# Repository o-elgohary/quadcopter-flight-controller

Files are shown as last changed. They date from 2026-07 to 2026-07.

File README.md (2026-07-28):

# Quadcopter Flight Controller

A 250mm-class quad flight controller, designed across three connected pieces: a custom PCB, a 3D-printed frame, and a control-systems simulation. None of this has been physically built or flown. It's a design and simulation project, stated plainly rather than implied otherwise.

## The integration story

The point of this project isn't any single piece, it's that each piece drove a real decision in another:

- **The simulation's control-loop speed requirement decided a wiring choice on the PCB.** The rate loop runs at 500Hz, which means the IMU needs to report data faster than 1kHz to keep up. That's why the ICM-42688-P is wired on SPI1 instead of I2C in the schematic, since I2C can't reliably keep pace with a loop that fast once you account for register-read overhead.
- **The PCB's real mounting-hole positions drove the CAD frame's geometry.** The board's STEP export (`pcb/exports/board.step`, once routing is finished) gets imported directly into the Fusion 360 frame model, and the center plate's mounting pattern is dimensioned straight off it, not measured by eye.
- **Every number in every phase traces back to one file, `spec.md`**, so a change to (say) the battery or frame size ripples outward instead of getting silently re-typed as a new assumption somewhere else.

## Repo layout

```
spec.md         master numbers every other file pulls from
pcb/            KiCad schematic + layout
cad/            exported Fusion 360 frame STEP
sim/            Python attitude-recovery simulation
```

## Status

| Phase | State |
|---|---|
| Spec (`spec.md`) | Done. Frame/motor/battery/IMU/MCU choices are real parts for this class of build; motor thrust/torque constants (kT, kQ) are documented estimates anchored to real bench-test data, not measured on this exact hardware. |
| PCB (`pcb/`) | Schematic done, ERC clean (0 errors, 2 benign warnings). Board outline, mounting holes, and component placement are done. Copper routing is not finished, so real DRC violations remain from auto-placement, left as the next real routing pass rather than papered over. |
| Frame (`cad/`) | Modeled in Fusion 360: center plate with the PCB's mounting pattern, 4 arms sized to the 250mm diagonal, motor mounts, battery deck. Exported to `cad/exports/frame_assembly.step`. Prop clearance checked analytically (adjacent motors clear by about 50mm at the prop tips). |
| Simulation (`sim/`) | A single-axis PD controller recovering a 20° tilt, settling in 0.13s. Deliberately simplified from an earlier, much larger 6-DOF version, see `sim/README.md` for why. Produces a plot (`sim/exports/recovery.png`). |

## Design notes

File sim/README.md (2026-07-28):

# Quadcopter Flight Controller - Simulation (Phase 3)

A minimal single-axis attitude simulation: a PD controller recovering a
quadcopter from an initial tilt. Simplified on purpose, see "Why simplified"
below. Every physical constant traces back to `../spec.md`.

## Files

| File | Role |
|---|---|
| `quad_sim.py` | Everything: constants, the PD control loop, and the plot. |

Run it from this `sim/` directory:

```
python -m venv .venv
.venv/Scripts/pip install -r requirements.txt
.venv/Scripts/python quad_sim.py
```

Writes `exports/recovery.png` (tilt angle vs. time, with the settling point
marked).

An animated version (drone icon banking back to level) was attempted but
dropped. matplotlib's GIF-writing path (`animation.PillowWriter`, a manual
canvas-buffer grab, and a `savefig`-per-frame plus Pillow `save_all` combine)
all silently produced a GIF where every frame showed the same final state,
in this specific environment. Root cause wasn't nailed down after several
different fixes, so the static plot below reliably shows the same result
without depending on that broken path.

## Results

Recovering from a 20 deg initial tilt, PD control settles within a 2 deg band
at **t = 0.13 s**.

Gains (in `quad_sim.py`): `KP = 0.5`, `KD = 0.035`. No integral term, since
this model is deliberately simple enough that a small P+D loop is enough to
show the point, and skipping I avoids windup entirely rather than adding an
anti-windup clamp for a demo this small.

## Why simplified

An earlier version of this modeled full 6-DOF coupled dynamics across 8 files
(quaternion attitude, IMU sensor noise, a complementary filter, cascaded
dual-rate PID, a 3D video render), around 700 lines. That was cut down to
this single ~110-line file on purpose. It keeps the same core idea (a
tilted quad correcting itself via feedback control) without machinery that
made the project harder to explain than it needed to be for its scope.

## What's estimated vs. from spec.md

From `spec.md` directly: mass (0.650 kg), arm length (0.125 m, half the
250 mm diagonal), control loop rate (500 Hz).

Estimated here (not in spec.md, no CAD to measure from): the per-axis
rotational inertia, modeled as just the 4 motors (30 g each) as point masses
at the arm tips, 45 deg off-axis in the X layout: `I = 4 * m_motor *
(ARM * sin(45°))^2`. This ignores the central body's own inertia contribution,
which is a real simplification, not an oversight. It keeps the number easy
to derive and explain, at the cost of being a slight underestimate. The PD
gains were tuned against this specific number, so if the inertia estimate is
refined later, the gains would need retuning too.

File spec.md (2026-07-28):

# Spec - Quadcopter Flight Controller

Every number used in `pcb/`, `cad/`, and `sim/` should trace back to this file. If you change something here, it should ripple out to the other phases, not get re-typed as a new magic number somewhere else.

## Airframe

| Parameter | Value |
|---|---|
| Frame class | 250 mm motor-to-motor diagonal (X config) |
| Motors | 2306, 2400 KV, 4x |
| Props | 5" (127 mm) |
| Battery | 4S LiPo, 1500 mAh, 14.8 V nominal |
| Target all-up weight (AUW) | ~650 g |
| Hover thrust per motor | ~1.6 N (650 g x 9.81 / 4) |

## Motor model

Real thrust-stand data for 2306/2400KV motors on 5" props (Emax RS2306 2400kv family, tested on miniquadtestbench.com) tops out around 1100-1400 g of thrust per motor at full throttle on 4S. That's the anchor point for the estimate below. I don't have a datasheet-grade thrust curve for this exact motor/prop/battery combo, so I derived kT and kQ instead of inventing precise-looking numbers. Treat these as reasonable-order-of-magnitude estimates, not verified hardware values.

Method:
- No-load speed at 4S: 2400 KV x 14.8 V ≈ 35,500 RPM. Under a real 5" prop load, racing motors typically sag to somewhere around 28,000 RPM at max sustained throttle.
- Picking max thrust ≈ 13 N (~1325 g, middle of the observed 1100-1400 g range) at ω_max ≈ 2930 rad/s gives:
  - **kT ≈ 1.5e-6 N·s²/rad²** (F = kT · ω²)
- Reaction torque (yaw authority) uses the common rule-of-thumb that a 5" multirotor prop's drag torque is roughly 3-8% of its thrust times the prop radius:
  - **kQ ≈ 7.5e-8 N·m·s²/rad²**
- Working these backwards, hover (1.6 N/motor) lands at ω_hover ≈ 1030 rad/s ≈ 9,800 RPM, which is about 28% of max RPM. That's a plausible hover throttle for a racing motor on a light 650 g frame (these motors are deliberately overpowered for punch-outs and recovery authority, so low hover throttle is expected, not a bug).
- Motor electrical/mechanical lag: **τ ≈ 0.02 s** (typical first-order response time for small FPV motor + ESC combos, per brief).

## Control loop rates

- Rate (inner) loop: 500 Hz
- Attitude (outer) loop: 250 Hz
- Rule used: IMU output data rate must be > 2x the fastest loop (500 Hz), so > 1 kHz minimum.

## IMU choice

ICM-42688-P, SPI. Datasheet specs (TDK InvenSense):
- Gyro noise density: 2.8 mdps/√Hz
- Accel noise density: 70 µg/√Hz
- Max ODR: 32 kHz (we'll run it far below that, e.g. 1-2 kHz, but it comfortably clears the >1 kHz requirement above)

This is why the IMU is on SPI1 rather than I2C in the schematic. I2C tops out well below what a 500 Hz rate loop wants once you account for register-read overhead.

## Barometer

BMP280 on I2C1 (altitude only, not latency-critical, so I2C is fine here).

## MCU

STM32F411CEU6, UFQFPN48. 100 MHz Cortex-M4F, enough headroom for 500 Hz control math plus sensor fusion.

## Board

- 36x36 mm outline
- 30.5x30.5 mm M3 mounting hole pattern (standard "FC30.5" footprint; this exact number is reused for the CAD frame's standoff pattern in Phase 2)

## Open assumptions to flag if anyone pushes back on this spec

- kT/kQ are derived estimates, not measured on this exact motor/prop/battery combination.
- τ (motor time constant) is a typical-value assumption, not measured.
- Everything else (frame size, battery, MCU, IMU, board size/hole pattern) is a normal, real part choice for this class of build.

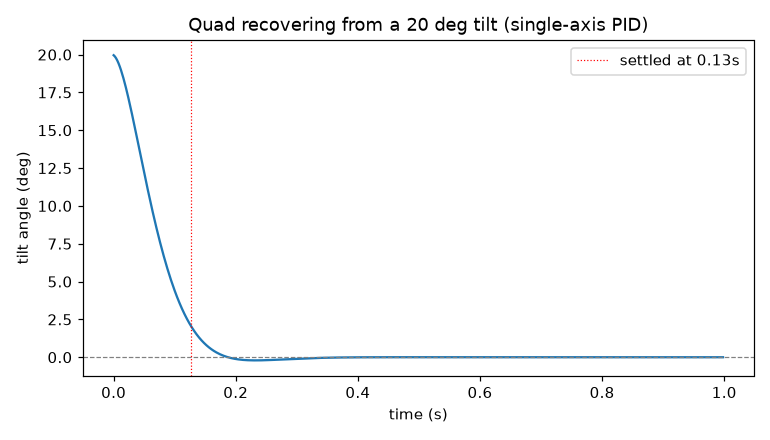
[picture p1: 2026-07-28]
sim/exports/recovery.png

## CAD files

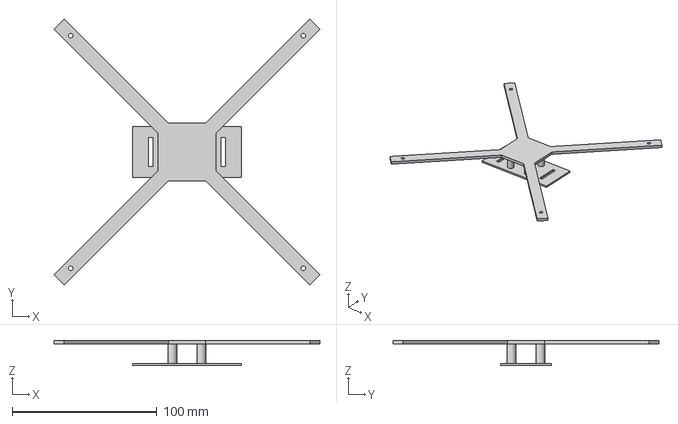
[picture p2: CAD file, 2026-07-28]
cad/exports/frame_assembly.step
183.8 x 183.8 x 17.5 mm

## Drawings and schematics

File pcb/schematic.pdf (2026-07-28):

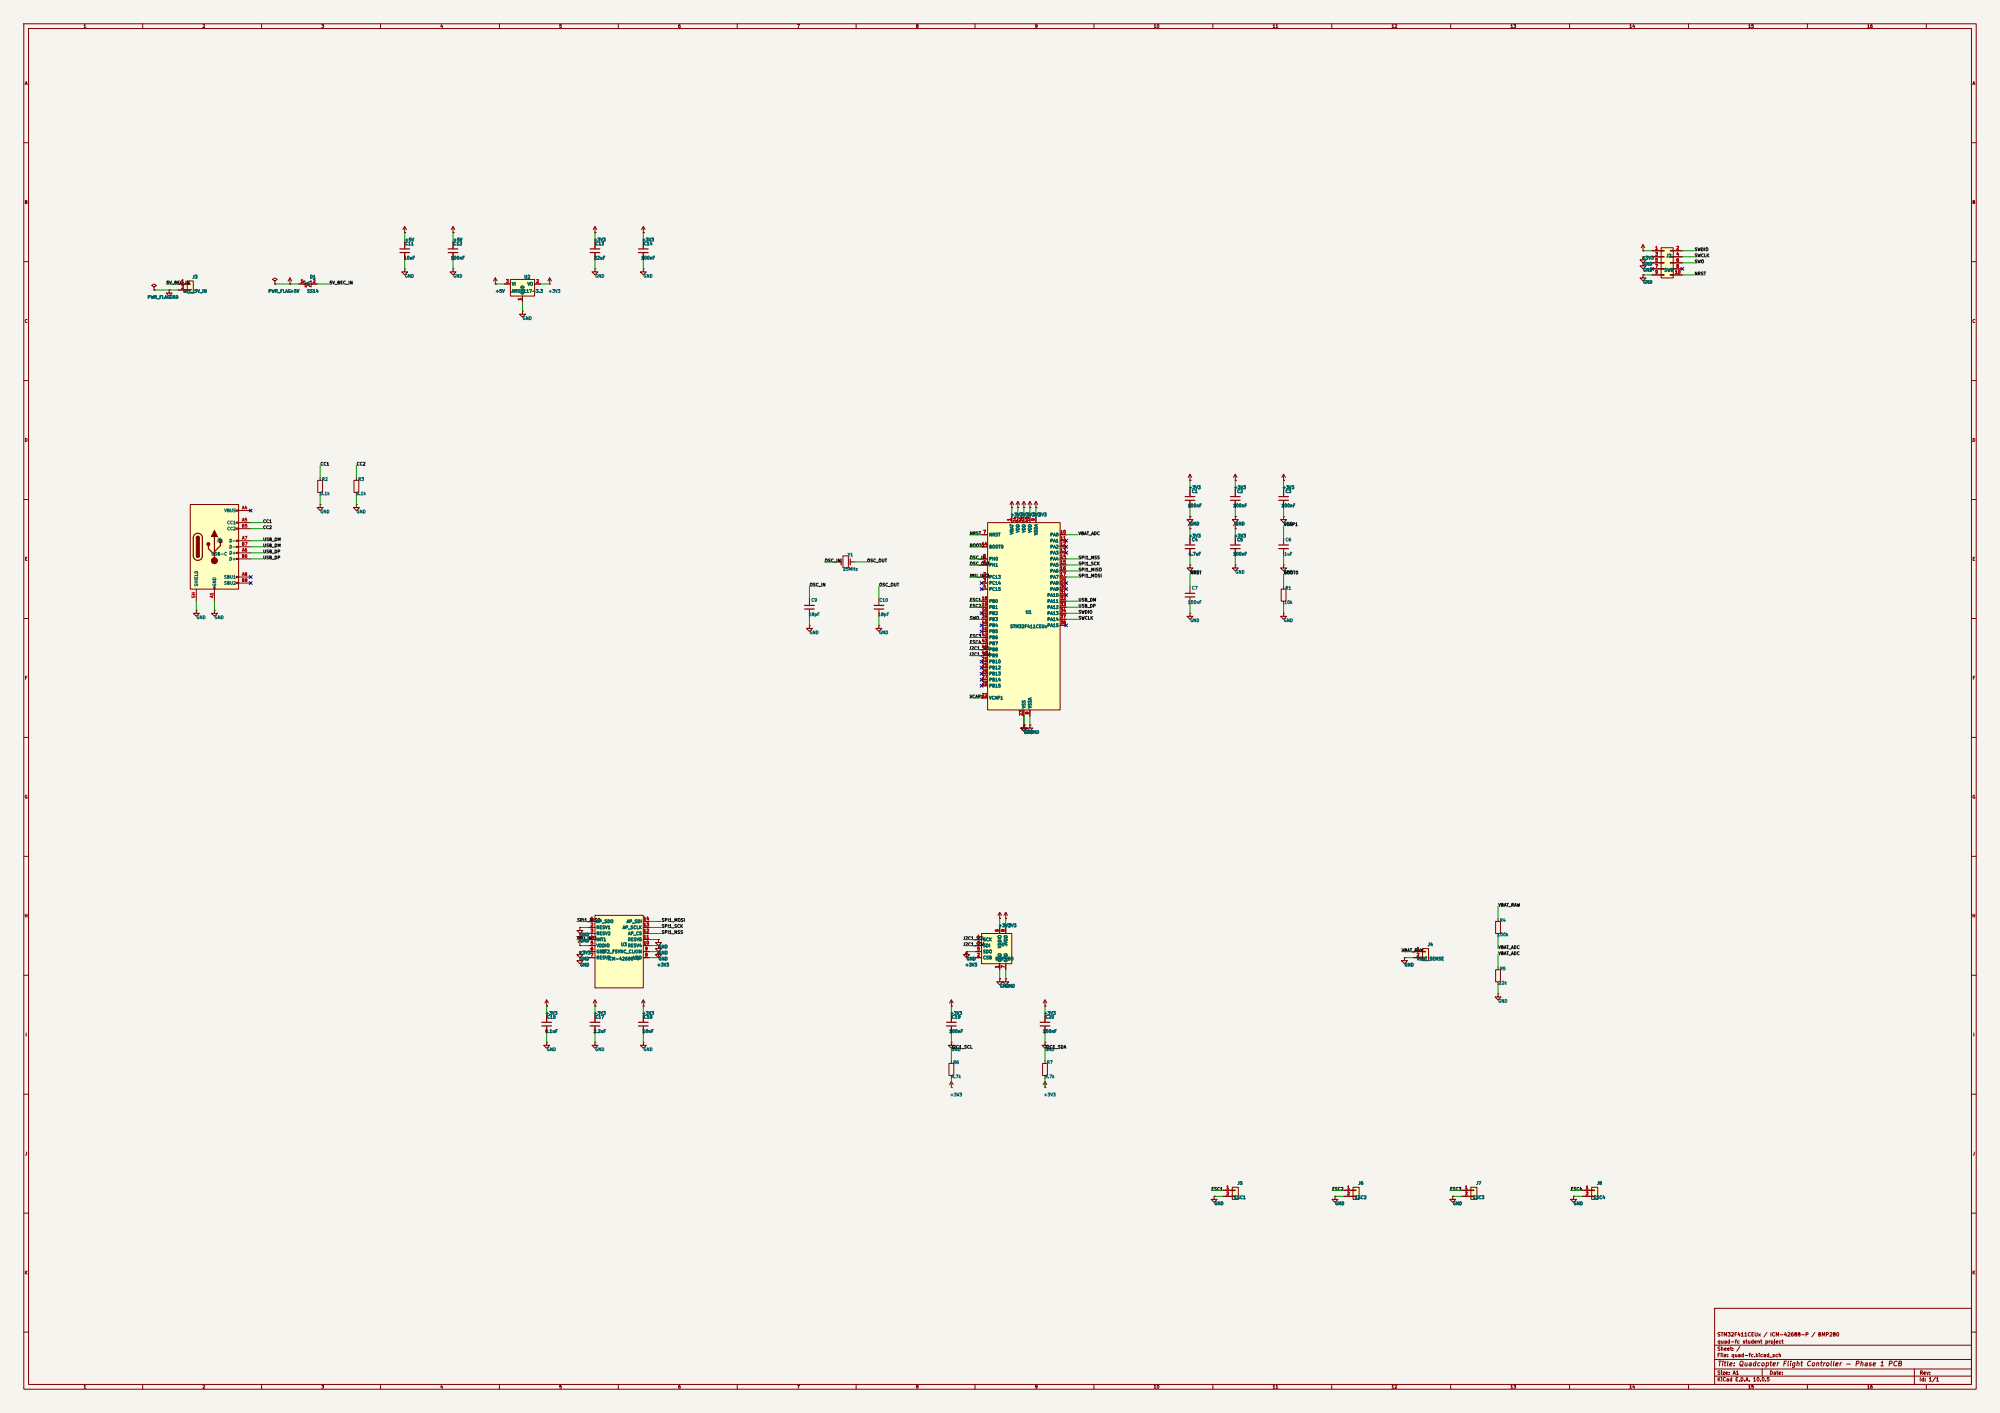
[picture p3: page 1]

STM32F411CEUx / ICM-42688-P / BMP280
quad-fc student project
Sheet: /
File: quad-fc.kicad_sch
Title: Quadcopter Flight Controller - Phase 1 PCB

Size: A1 | Rev:
KiCad E.D.A. 10.0.5 | Id: 1/1

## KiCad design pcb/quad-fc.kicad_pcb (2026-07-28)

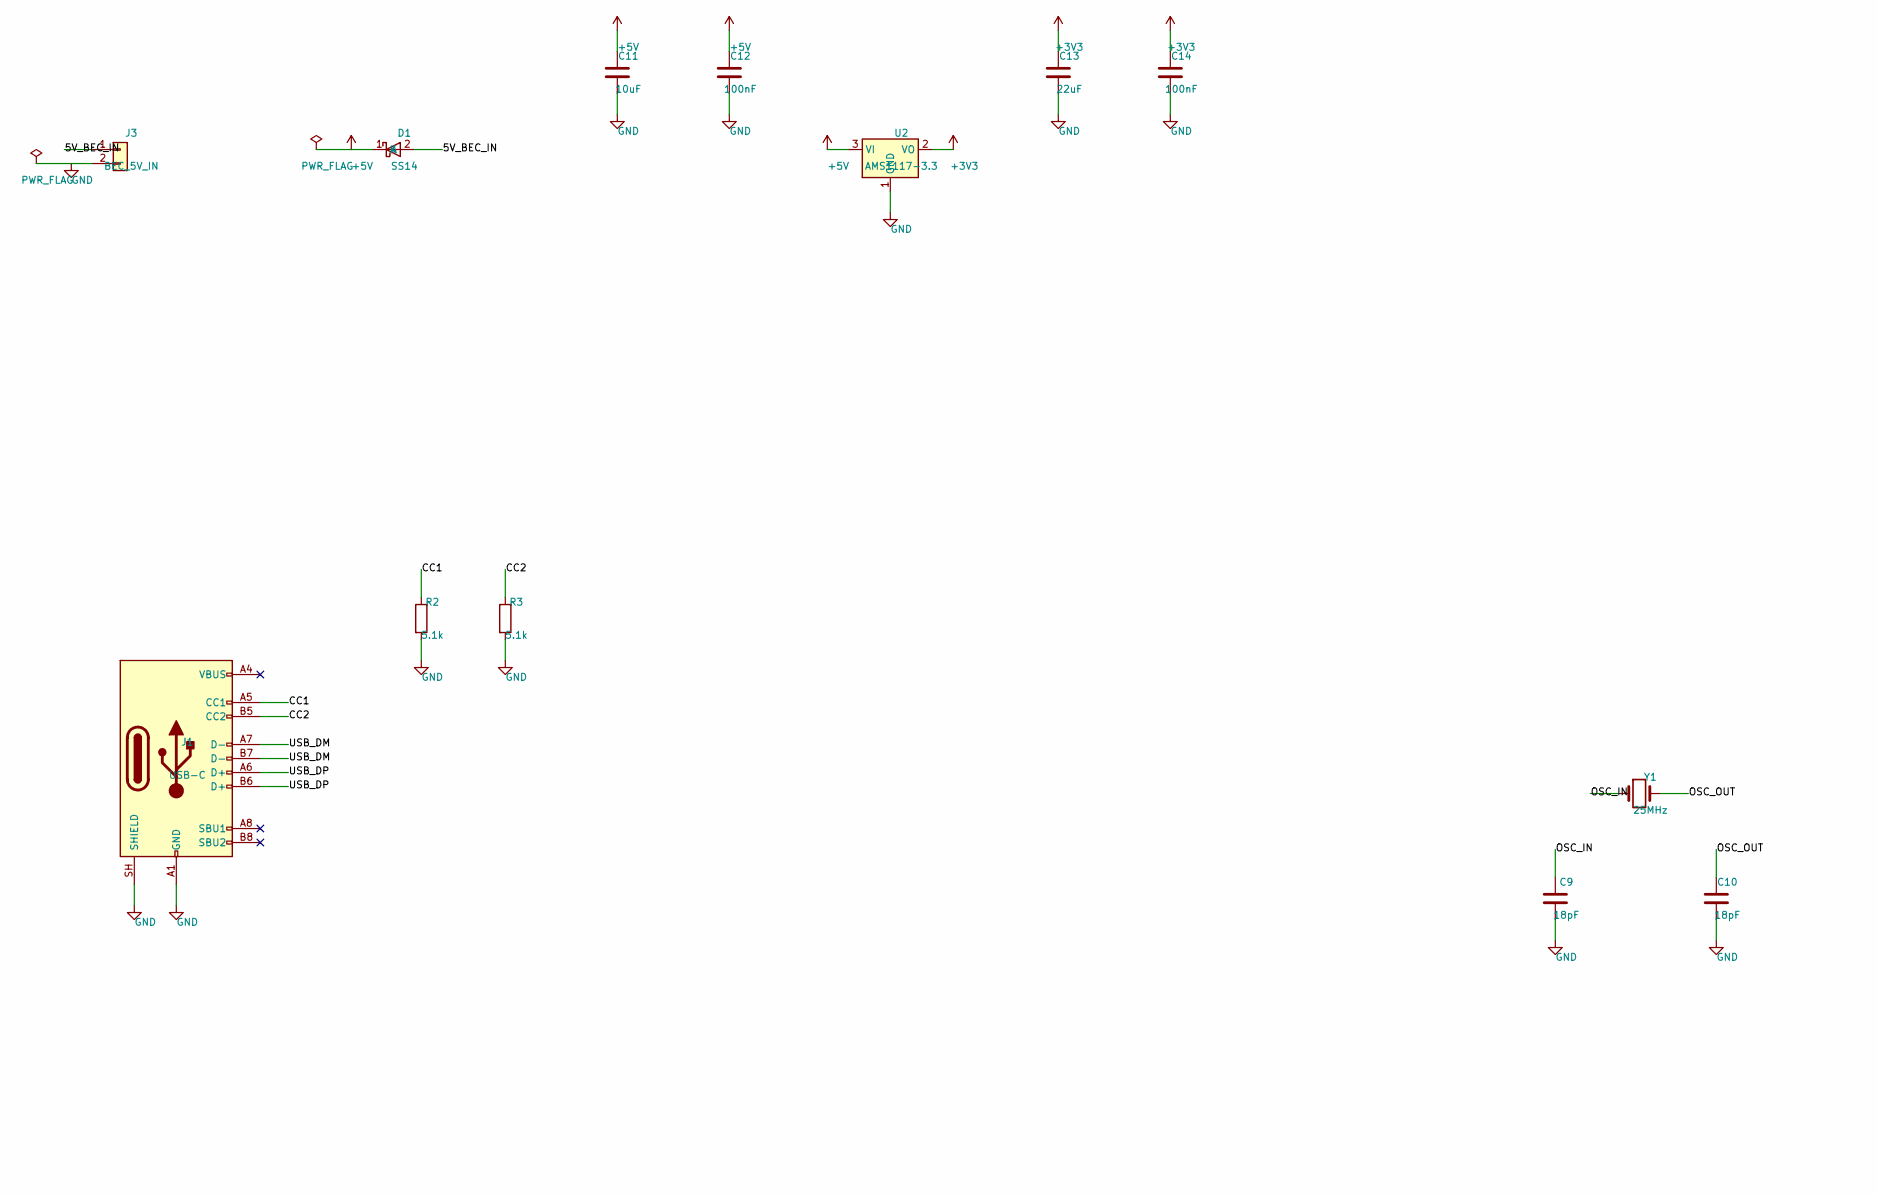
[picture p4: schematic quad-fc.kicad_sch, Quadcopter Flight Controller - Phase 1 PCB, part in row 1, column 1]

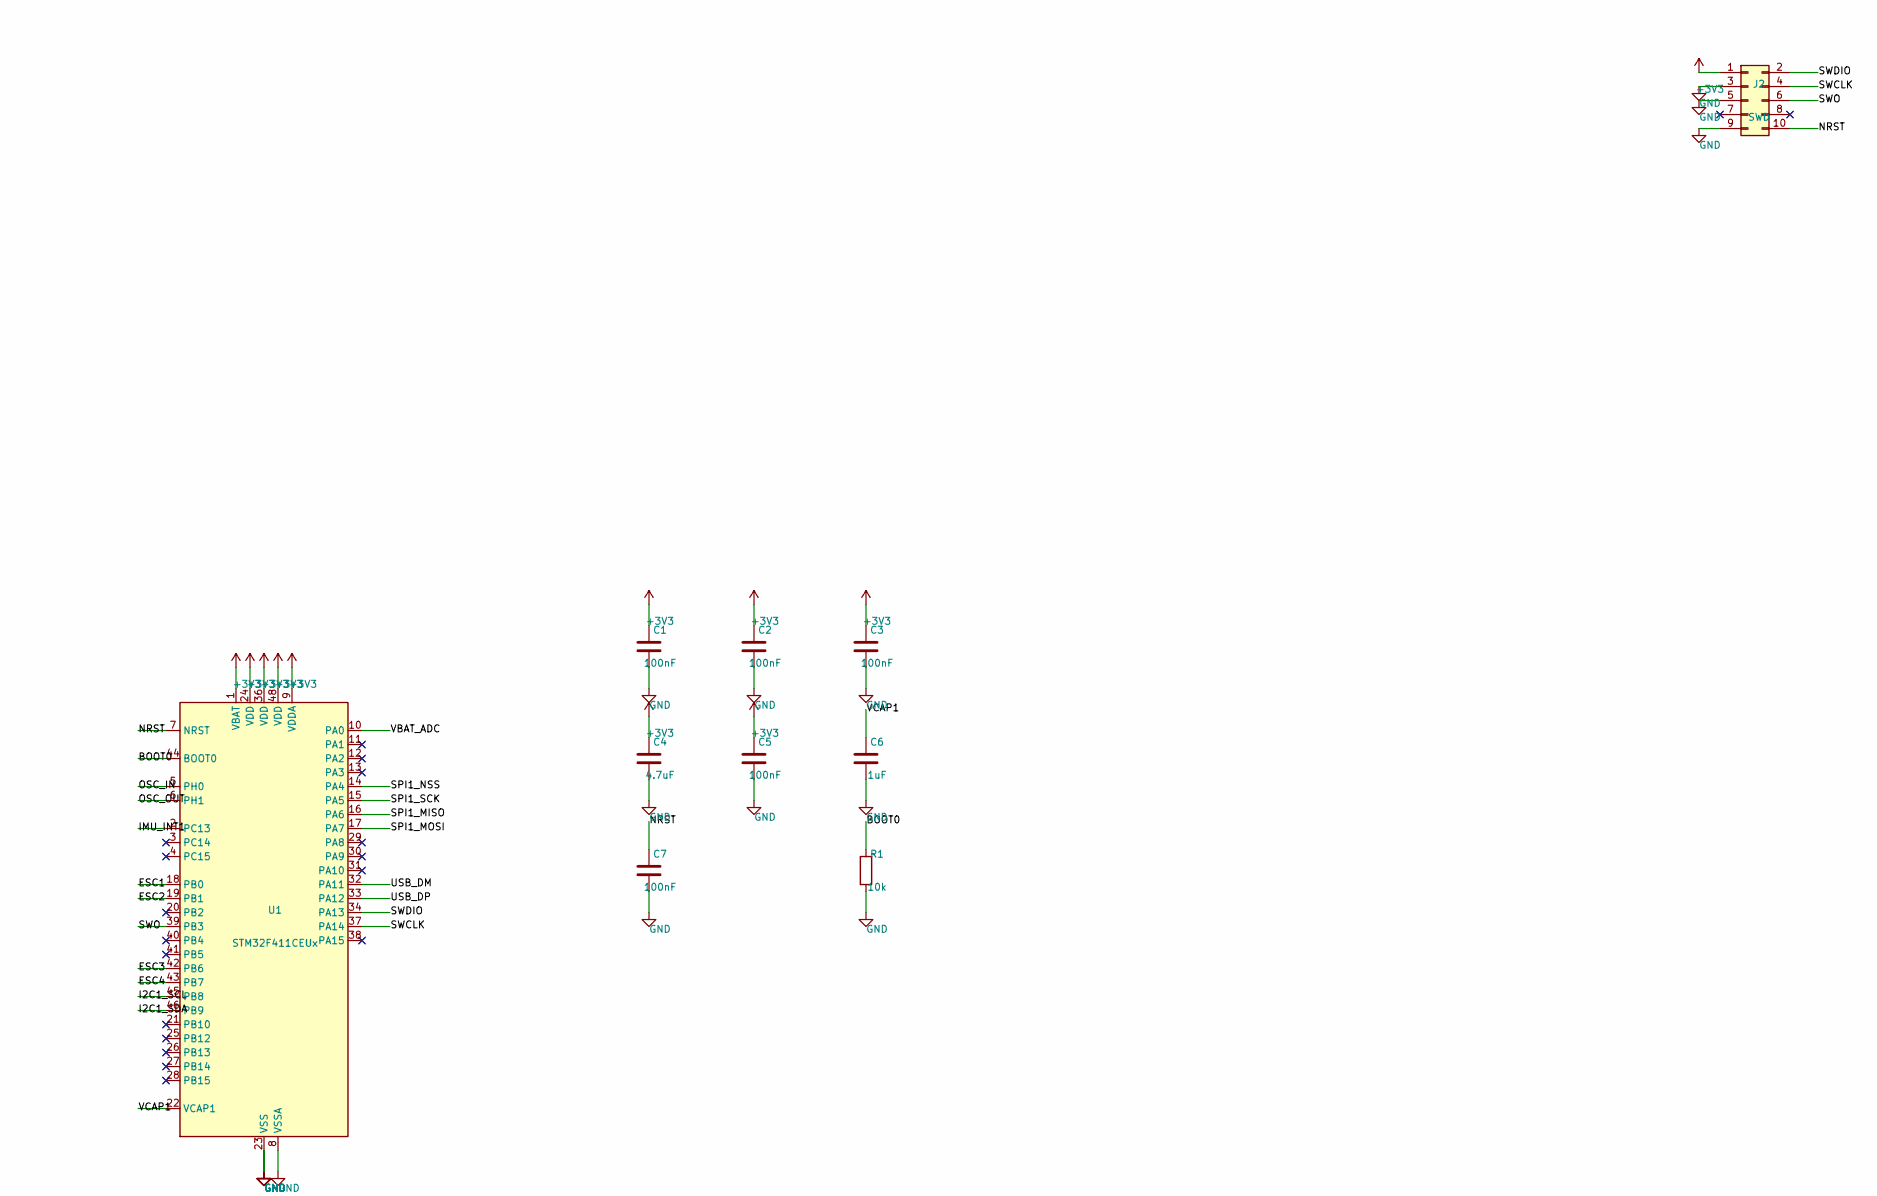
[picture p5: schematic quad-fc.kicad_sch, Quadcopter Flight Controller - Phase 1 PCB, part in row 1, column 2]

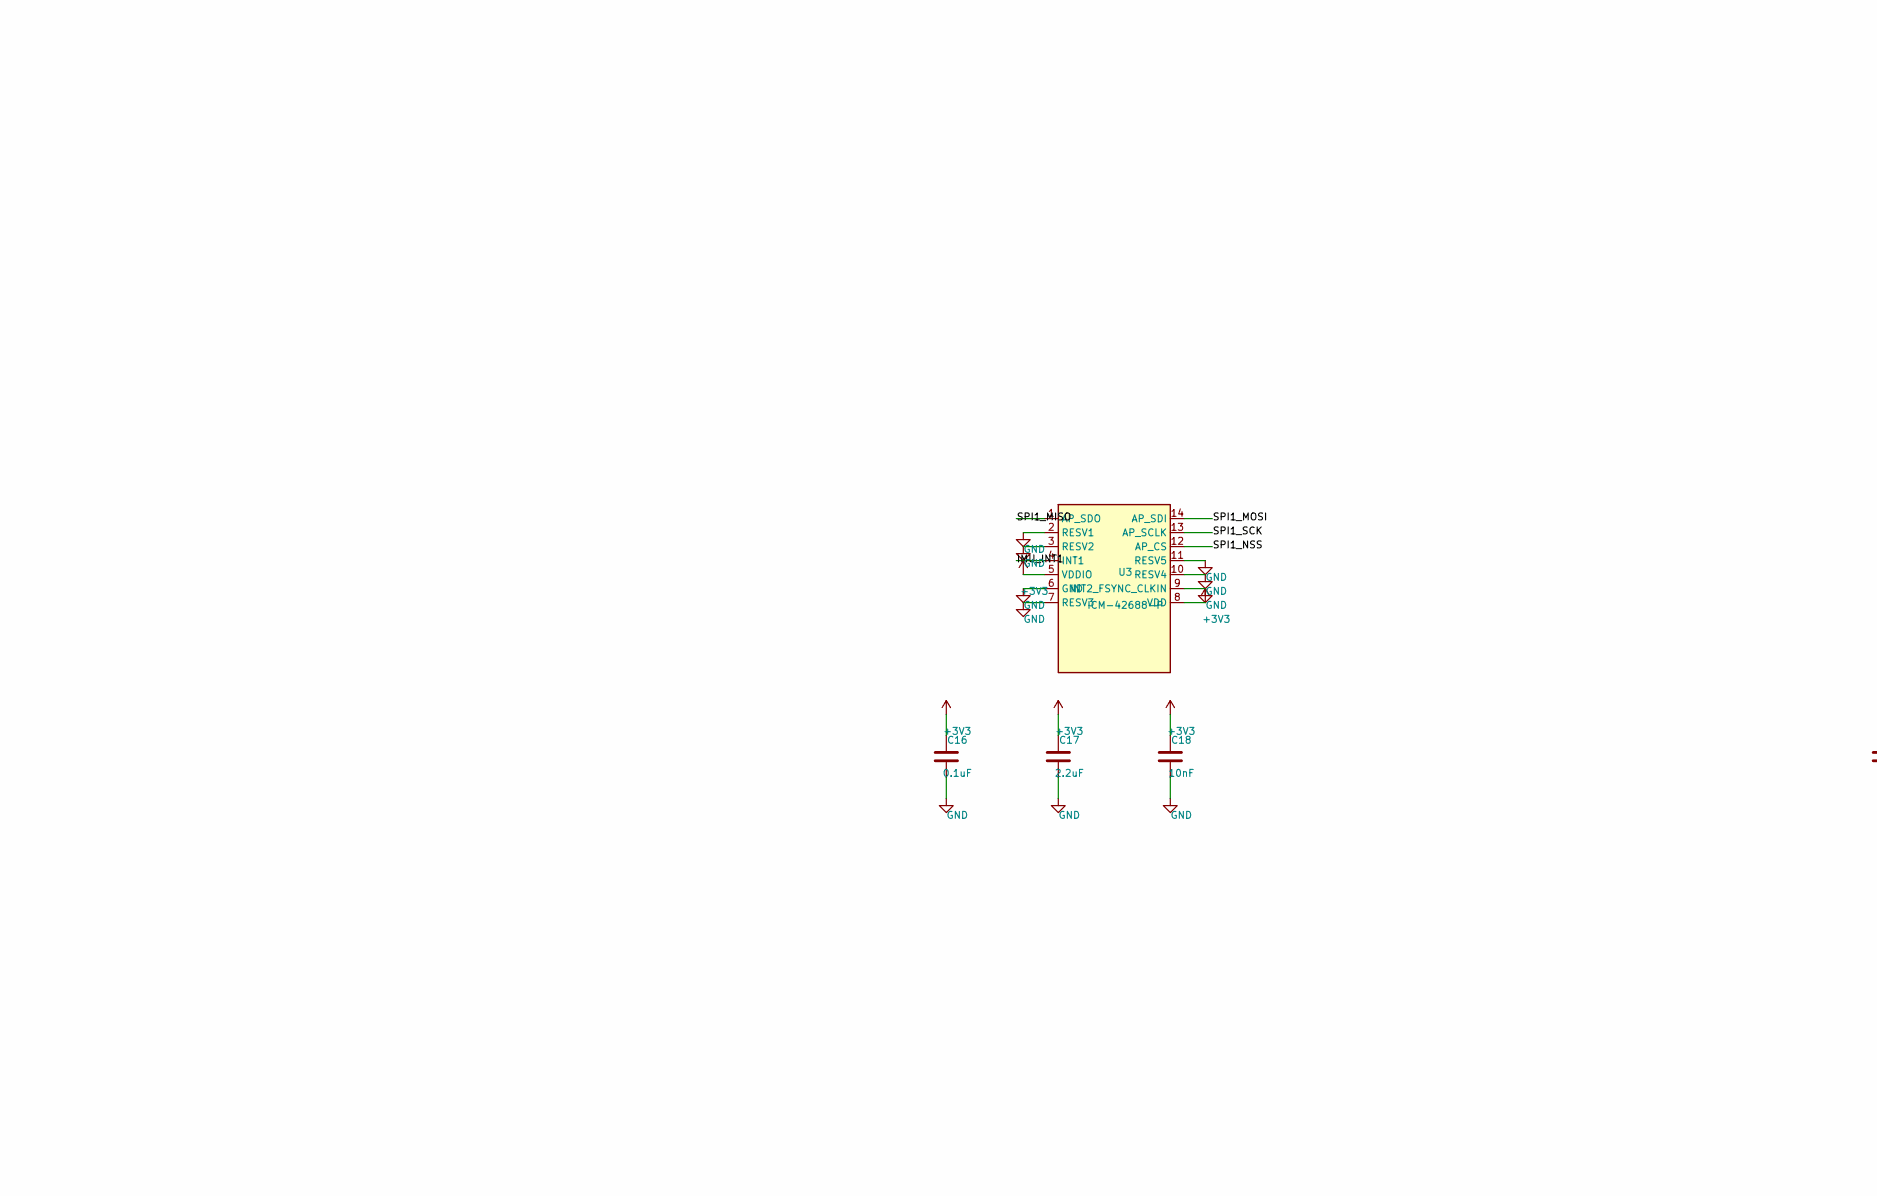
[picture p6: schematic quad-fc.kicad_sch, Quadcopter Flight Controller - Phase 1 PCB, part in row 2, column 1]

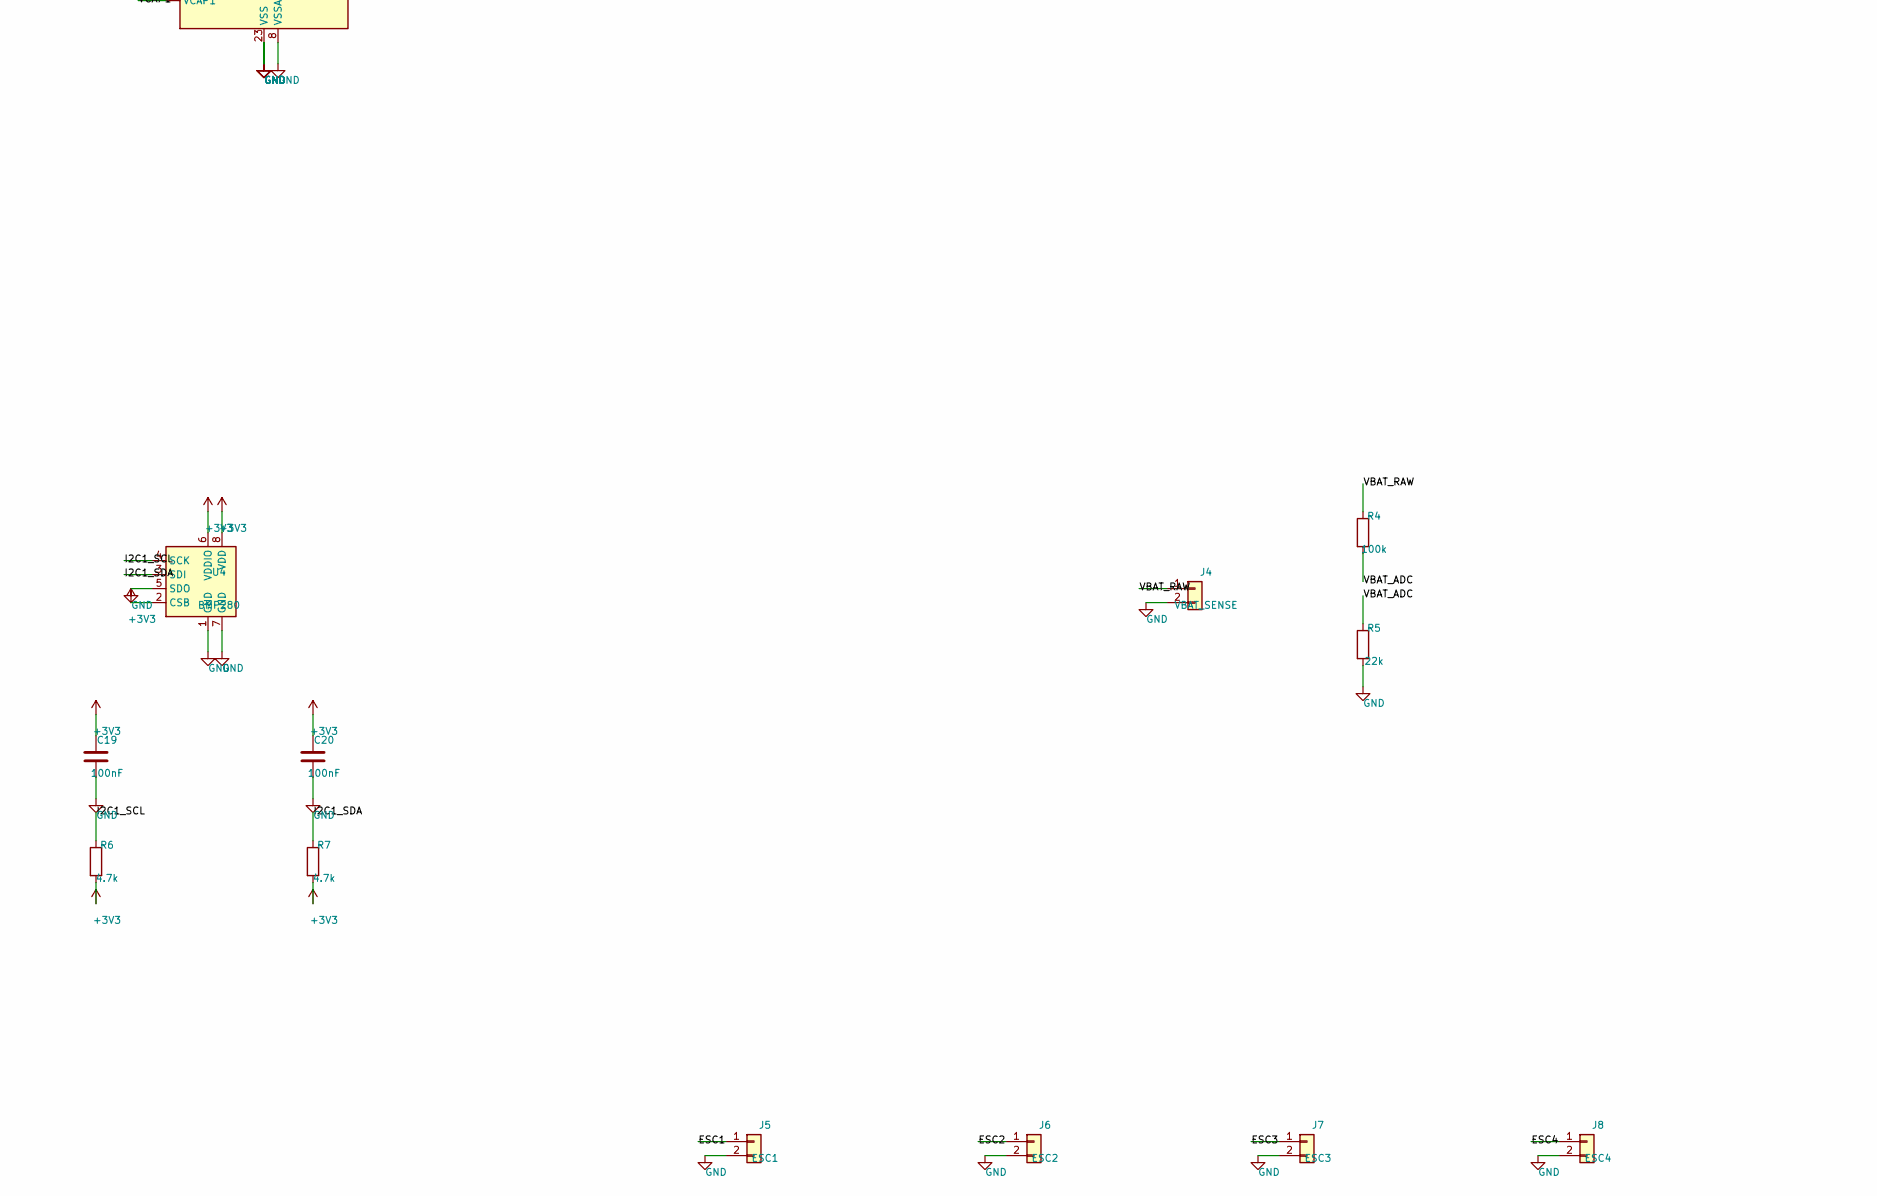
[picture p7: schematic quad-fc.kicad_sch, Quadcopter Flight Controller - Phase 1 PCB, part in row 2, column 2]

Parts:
C1, C2, C3, C5, C7, C12, C14, C19, C20: 100nF; C_0603_1608Metric
C4: 4.7uF; C_0805_2012Metric
C6: 1uF; C_0603_1608Metric
C9, C10: 18pF; C_0603_1608Metric
C11: 10uF; C_0805_2012Metric
C13: 22uF; C_0805_2012Metric
C16: 0.1uF; C_0603_1608Metric
C17: 2.2uF; C_0805_2012Metric
C18: 10nF; C_0603_1608Metric
D1: SS14; D_SMA
J1: USB-C; USB_C_Receptacle_GCT_USB4105-xx-A_16P_TopMnt_Horizontal
J2: SWD; PinHeader_2x05_P1.27mm_Vertical
J3: BEC_5V_IN; PinHeader_1x02_P2.54mm_Vertical
J4: VBAT_SENSE; PinHeader_1x02_P2.54mm_Vertical
J5: ESC1; PinHeader_1x02_P2.54mm_Vertical
J6: ESC2; PinHeader_1x02_P2.54mm_Vertical
J7: ESC3; PinHeader_1x02_P2.54mm_Vertical
J8: ESC4; PinHeader_1x02_P2.54mm_Vertical
R1: 10k; R_0603_1608Metric
R2, R3: 5.1k; R_0603_1608Metric
R4: 100k; R_0603_1608Metric
R5: 22k; R_0603_1608Metric
R6, R7: 4.7k; R_0603_1608Metric
U1: STM32F411CEUx; QFN-48-1EP_7x7mm_P0.5mm_EP5.6x5.6mm
U2: AMS1117-3.3; SOT-223-3_TabPin2
U3: ICM-42688-P; LGA-14_3x2.5mm_P0.5mm_LayoutBorder3x4y
U4: BMP280; Bosch_LGA-8_2x2.5mm_P0.65mm_ClockwisePinNumbering
Y1: 25MHz; Crystal_SMD_3215-2Pin_3.2x1.5mm

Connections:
5V_BEC_IN: D1.2 (A), J3.1
+3V3: C1.1, C2.1, C3.1, C4.1, C5.1, C13.1, C14.1, C16.1, C17.1, C18.1, C19.1, C20.1, J2.1, R6.2, R7.2, U1.1 (VBAT), U1.9 (VDDA), U1.24 (VDD), U1.36 (VDD), U1.48 (VDD), U2.2 (VO), U3.5 (VDDIO), U3.8 (VDD), U4.2 (CSB), U4.6 (VDDIO), U4.8 (VDD)
+5V: C11.1, C12.1, D1.1 (K), U2.3 (VI)
BOOT0: R1.1, U1.44 (BOOT0)
CC1: J1.A5 (CC1), R2.1
CC2: J1.B5 (CC2), R3.1
ESC1: J5.1, U1.18 (PB0)
ESC2: J6.1, U1.19 (PB1)
ESC3: J7.1, U1.42 (PB6)
ESC4: J8.1, U1.43 (PB7)
GND: C1.2, C2.2, C3.2, C4.2, C5.2, C6.2, C7.2, C9.2, C10.2, C11.2, C12.2, C13.2, C14.2, C16.2, C17.2, C18.2, C19.2, C20.2, J1.A1 (GND), J1.A12 (GND), J1.B1 (GND), J1.B12 (GND), J1.SH (SHIELD), J2.3, J2.5, J2.9, J3.2, J4.2, J5.2, J6.2, J7.2, J8.2, R1.2, R2.2, R3.2, R5.2, U1.8 (VSSA), U1.23 (VSS), U1.35 (VSS), U1.47 (VSS), U1.49 (VSS), U2.1 (GND), U3.2 (RESV1), U3.3 (RESV2), U3.6 (GND), U3.7 (RESV3), U3.9 (INT2_FSYNC_CLKIN), U3.10 (RESV4), U3.11 (RESV5), U4.1 (GND), U4.5 (SDO), U4.7 (GND)
I2C1_SCL: R6.1, U1.45 (PB8), U4.4 (SCK)
I2C1_SDA: R7.1, U1.46 (PB9), U4.3 (SDI)
IMU_INT1: U1.2 (PC13), U3.4 (INT1)
NRST: C7.1, J2.10, U1.7 (NRST)
OSC_IN: C9.1, U1.5 (PH0), Y1.1
OSC_OUT: C10.1, U1.6 (PH1), Y1.2
SPI1_MISO: U1.16 (PA6), U3.1 (AP_SDO)
SPI1_MOSI: U1.17 (PA7), U3.14 (AP_SDI)
SPI1_NSS: U1.14 (PA4), U3.12 (AP_CS)
SPI1_SCK: U1.15 (PA5), U3.13 (AP_SCLK)
SWCLK: J2.4, U1.37 (PA14)
SWDIO: J2.2, U1.34 (PA13)
SWO: J2.6, U1.39 (PB3)
USB_DM: J1.A7 (D-), J1.B7 (D-), U1.32 (PA11)
USB_DP: J1.A6 (D+), J1.B6 (D+), U1.33 (PA12)
VBAT_ADC: R4.2, R5.1, U1.10 (PA0)
VBAT_RAW: J4.1, R4.1
VCAP1: C6.1, U1.22 (VCAP1)

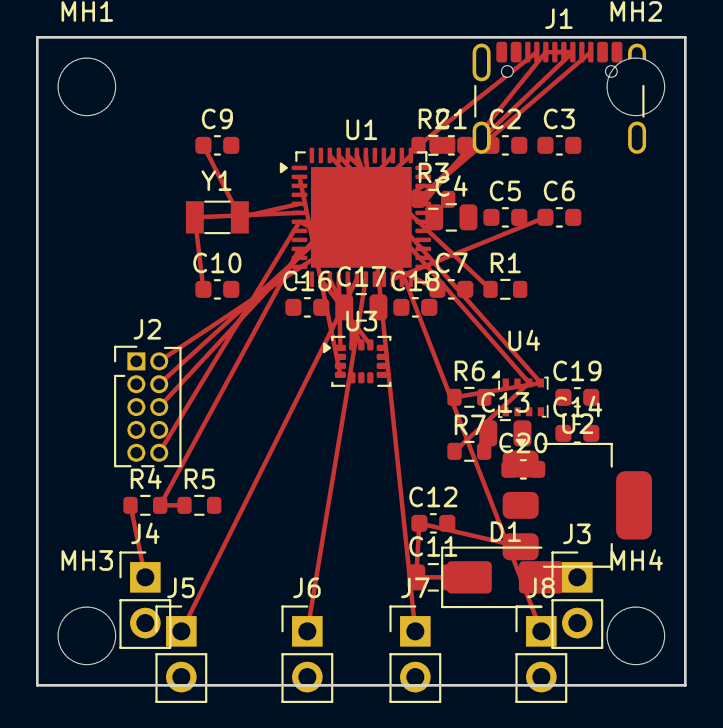
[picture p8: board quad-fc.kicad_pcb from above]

Board: 2 copper layers, 36.0 x 36.0 mm, 43 parts (0 on the bottom side), 29 nets.

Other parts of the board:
MH1, MH2, MH3, MH4: M3; MountingHole_3.2mm_M3
